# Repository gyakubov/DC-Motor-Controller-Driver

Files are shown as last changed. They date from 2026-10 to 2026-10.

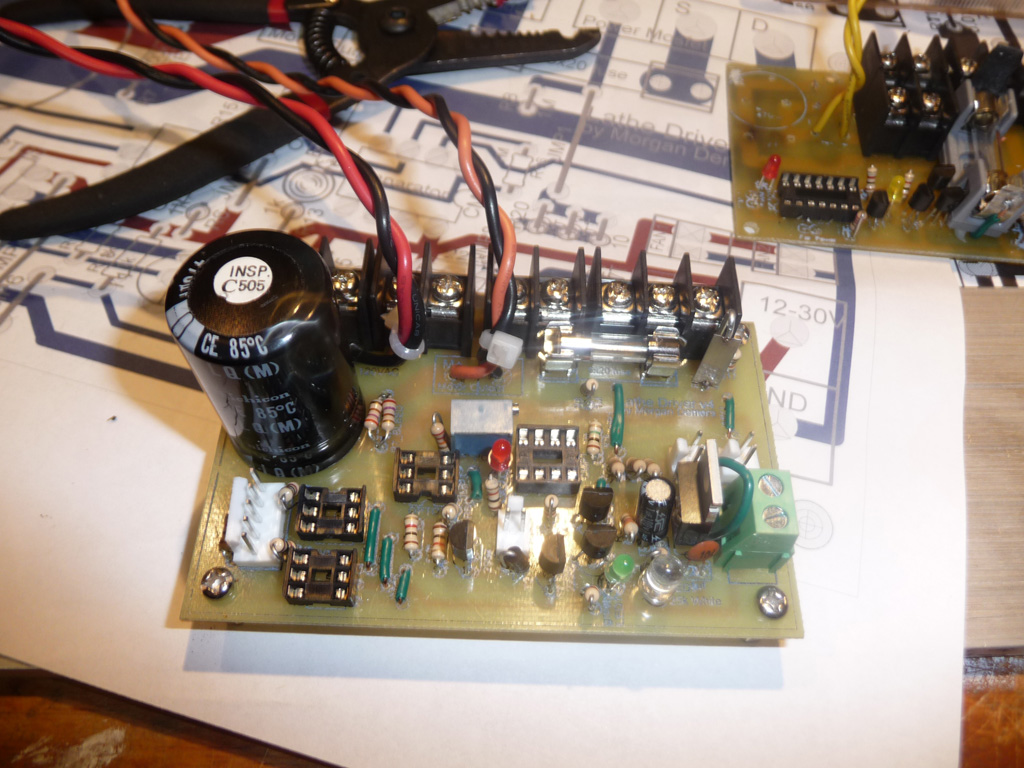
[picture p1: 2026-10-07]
Hardware/Photos/DRIVER_POPULATED.JPG

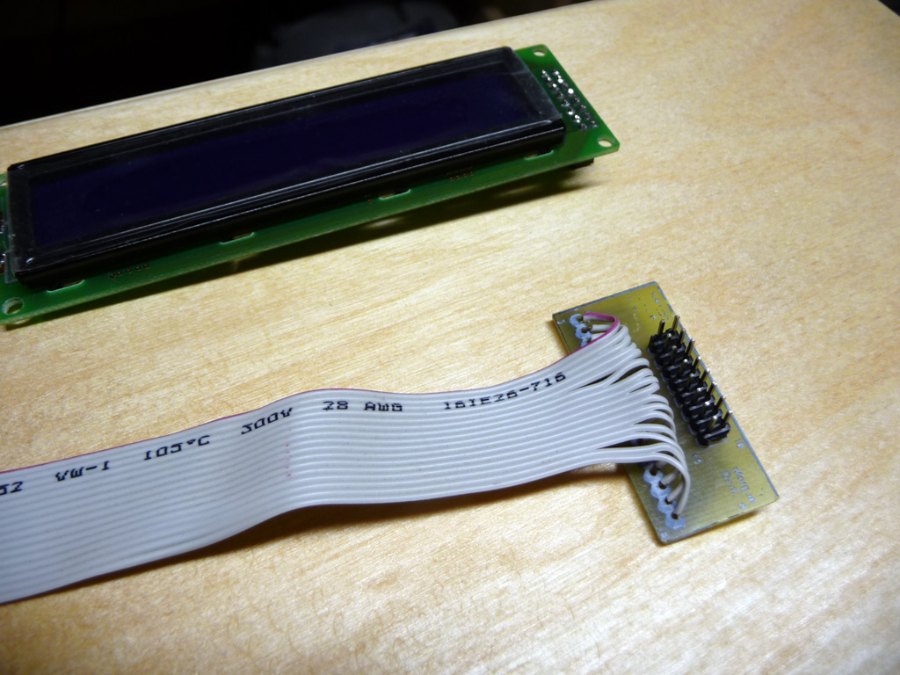
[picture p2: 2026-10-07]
Hardware/Photos/2x8_header_to_1x16_ribbon_and_LCD.jpg

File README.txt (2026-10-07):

DC Motor Controller & Driver README
===================================

This directory has the open source DC Motor Controller & Driver software, board layouts, schematics, and parts list.

For the latest updates by the original author of this project visit:
http://morgandemers.com/?page_id=444

Author: Morgan Demers

+---------+
| LICENSE |
+---------+

This work is licensed under the Creative Commons Attribution-NonCommercial-ShareAlike 3.0 Unported License. To view a copy of this license, visit http://creativecommons.org/licenses/by-nc-sa/3.0/.

+--------------+
| Introduction |
+--------------+

In the winter of 2009 I began working on a Gingery Style metal lathe, as an alternative to buying a chinese made 7x12. It was my desire to attain some casting and machining skills, and in the end to have a lathe with similar capabilities. The original Gingery design calls for cone pulleys and belt changes to get varying speeds with no compensation for load. As I have a background in Computer Engineering, I thought it would be a great opportunity to design a Controller & Driver for a 2hp DC Treadmill Motor for the Lathe. I also wanted a fairly nice & simple digital interface that I could use to control the machine tool. And thus in 2011 I began working on the electronics / software aspect of the project. It is now 2013, my lathe is built, and the Controller, Driver and Software fairly well tested. It has been my end goal to make the project available to anyone who is interested in building a similar Controller for their own machine tool ( this can be used on a lathe, milling machine, drill press, etc... ).

+--------------+
| Dependencies |
+--------------+

Software:

The software was written for the Microchip PIC18LF14K50 Microcontroller, and was developed in the MPLAB v8.76 IDE for the Microchip C18 compiler ( free / lite version ). It may be possible to use MPLAB X, however I have not tested it yet...

I use a PICkit2 to program the Controller. I'd imagine a PICkit3 would work fine as well...

Hardware:

The Board Layouts & Schematics are all done in the free / lite version of Eagle 6.1.0. 

+---------------+
| Prerequisites |
+---------------+

In order to build the Controller / Driver you will need some skills / tools. You should have some experience with etching your own printed circuit boards, soldering on components, etc... I've made a point to not use SMD components to make it a bit easier for those who might have through-hole experience, but not SMD...

To get the software onto the controller you will need a PICkit2 ( or PICkit3 ) programmer. At the very least you will need the PICkit2 programmer software to install the 'hex' file in the Sofware Directory, or you will need the MPLAB IDE with C18 compiler installed to build the project and program the Controller.

To print the board layouts you will need Eagle v6.1.0 ( or newer ).

I've made a point to design the Controller / Driver within the limitations of the free versions of MPLAB IDE, C18 Compiter, Eagle v6.1.0, and thus you should not have to buy any software to get this project to work.

+---------------------+
| Directories & Files |
+---------------------+

LICENSE.txt - contains the license for this piece of software & hardware. Please read, open source though not for commercial use. If making modifications maintain changelog, and please leave the names of prior authors, and url to original source ( http://morgandemers.com/?page_id=444 )

README.txt - this file

Parts_List.xls - Excel Spreadsheet of all the parts required to build the Controller / Driver / Interface

Parts_List.csv - CSV version of Excel Sheet if you don't have Excel

'Software' folder - Contains the PIC18LF14K50 C18 software for the Controller. Load MPLAB v8.76 project file, or you can find pre-compiled HEX file that you could download directly to the Controller board.

'Hardware' folder - Contains all Eagle v6.1.0 Schematics & Board Layouts for this project

'Hardware/Eagle Libraries' folder - Contains any Eagle Library dependencies - only used for QRD1114 part in 'Tachometer' schematic / board.

'Hardware/Photos' folder - Contains some photos of my controller / boards / etc... A bit weak but thought it would be relevant to include some photos.

Hardware/Controller.{sch|brd} - Controller Schematic / Board.

Hardware/Driver.{sch|brd} - Driver Schematic / Board.

Hardware/Tachometer.{sch|brd} - Tachometer Schematic / Board.

Hardware/120VAC.sch - Mains 120VAC connection to Driver Schematic

Hardware/Motor.sch - Connections from Motor to Forward/Reverse Relay to Driver Schematic

Hardware/LCD.sch - Connections from LCD to 2x8_to_1x16 board to 1x16_to_1x16 board to Controller Schematic

Hardware/Interface.sch - Connections from 3 interface buttons and RPM potentiometer to 1x9_to_1x9 board to Controller Schematic

'Encoder Wheels' folder - Contains some sample pdf files of Encoder Wheels that you can print out. I would also recommend you download this encoder wheel software that I currently use to create all my wheels at this point - http://code.google.com/p/wheel-encoder-generator/

+-------------------------+
| Putting It All Together |
+-------------------------+

At some point I may produce a video tutorial of building the controller, driver boards, programming the controller, and hooking everything up to a treadmill motor. That being said, it hasn't been done yet, though you can follow the steps below to get an idea of how to go about building the Controller / Driver.

The Circuit Boards were all made at home using the Toner Transfer Method. I've had fairly good success with Staples Photo Basic Gloss paper and a cheap Laminator that I purchased at Costco. I use Ferric Chloride to etch my boards, and have had no problem doing so. I have recently become aware that the 'Staples Photo Basic Gloss' paper is no longer available, but similar results should be capable when using a Glossy Color Laser paper.

Some suggestions:

i. Heatshrink tubing is a great way to insulate all high voltage wires.
ii. 1/4" Quick Disconnect Connectors work well for 120VAC & Motor Connections ( my treadmill motor came with 1/4" quick disconnects ).

Step 1: LCD
-----------
*refer to LCD.sch, 2x8_to_1x16.{sch|brd}, 1x16_to_1x16.{sch|brd} in Hardware folder for details

a. Start by soldering on the 2-1x8 female headers ( if you purchased the LCD display with the 2x8 solder pads ).

b. Make a 2x8_to_1x16 PCB. You should cut a sufficient length of 16 conductor ribbon cable and solder one end to the 2x8_to_1x16 PCB. The 2x8 male pins will connect directly onto the LCD's female header that you soldered in (a) ( take a look at Hardware/Photos to get an idea of how this looks ).

c. Make a 1x16_to_1x16 PCB. Solder the other end of the ribbon cable to the solder pads on the 1x16_to_1x16 PCB. You will solder on a 1x16 male pin header which will connect to the Controller.

Step 2: Interface
-----------------
*refer to Interface.sch, 1x9_to_1x9.{sch|brd} in Hardware folder for details

a. Make a 1x9_to_1x9 PCB. Make note of the Interface Component positions from the Interface.sch. I'll repeat here for clarity - Pins {1,2} connect to Right Button ( SPST momentary push button - NO ), Pins {3,4} connect to Menu Button ( SPST momentary push button - NO ), Pins {5,6} connect to Left Button ( SPST momentary push button - NO ), Pins {7,8,9} connect to RPM Adjustment Precision Potentiometer ( 5k, Multi-Turn ) - Pin 7 = Ground, Pin 8 = V+, Pin 9 = Variable Pot Voltage.

b. Solder a 1x9 male pin header to the other end of the 1x9_to_1x9 PCB, this will connect to the Controller's 'INTERFACE' header.

Step 3: Controller
------------------
*refer to Controller.{sch|brd} in Hardware folder for details

a. Make the 'Controller' PCB, and solder on the components - Do not insert M1 ( PIC18LF14K50 ) until you do (d) below...

b. Connect the Interface 1x9_to_1x9 PCB to the 'INTERFACE' female header on the Controller.

c. Connect the 1x16_to_1x16 PCB to the 'LCD' female header on the Controller.

d. Connect +5V power to POWER terminal block, hook a multimeter up to VTEST, and adjust P1 until you get 3.4V ( *only if using a PIC18LF... )

e. Turn off +5V power, insert M1 ( PIC18LF14K50 )

f. Connect PICKIT2, Load MPLAB or PICKIT2 Programmer Software. PIC18LF14K50 should be detected.

g. Load the 'DC Motor Controller' software into MPLAB, and Program the PIC18LF14K50

h. Once programmed, disconnect the PICKIT2, LCD should show welcome message ( might have to cycle power first )

i. If 'welcome message' displayed, and now on 'RPM: 0','TRG: ...' menu, test the Interface Buttons, otherwise you will have to debug the Controller Board - possibly bad trace, connection, or misplaced components...

*How to use the interface - Menu Button rotates between sub-menus, and Holding the Menu Buttons and pressing Left or Right will change the main menu. Left and Right buttons alone either increment or decrement menu items, or do other actions as suggested on the LCD ( such as start or stop the motor ).

j. Connect your multimeter to the VTEST ( ground pin ) and the PWM Out pin of the 'DRIVER_OUT' header. On the main menu, set the RPM with the RPM Potentiometer, and then press the 'Left Button' to start the motor. You should see a change in voltage on the multimeter. If you have a Frequency measurement feature, use that to verify the 25khz frequency.

Step 4: Tachometer
------------------
*refer to Tachometer.{sch|brd} in Hardware folder for details

a. Make the 'Tachometer' PCB, and solder on the components. This board is a bit tricky, as it has 2 boards in 1 - you will cut off the smaller board that has the QRD1114, and then solder that board onto the main board such that the QRD1114 is facing outward ( toward the encoder wheel, at least in my setup ).

b. You can cut out a set of 3 conductors from your 16 conductor ribbon cable for the Tachometer cable. Using the 3-pin Molex .100 ( 2.54mm ) KK crimp terminals & housings, create a cable to connect the Tachometer to the Controller via the 'TACH' Male Header.

c. Using a laser printer ( or inkjet, then copied on a laser copier ) print out '16_transistion.pdf' from the 'Encoder Wheels' folder.

d. Connect the Tachometer to the Controller, and then move the encoder wheel printout from (c) in front of the QRD1114 sensor ( needs to be very close to the encoder 1/8" or less ). While transitioning between black & white monitor the LCD to see if the RPM changes at all. You can also go to the second menu ( HOLD Menu and press the Right Button ), then the 3rd sub_menu ( press Menu 3 times ). It should have 'TRG: ..' and 'ENC: ..' displayed. While moving the wheel in front of the sensor you should see the ENC number change ( that is what it is seeing on the encoder in a given sample ).

Step 5: Driver
--------------
*refer to Driver.{sch|brd}, Motor.sch in Hardware folder for details

a. Make the 'Driver' PCB, and solder on the components. Note that AC1, AC2, M+, M- are wire pads, and should have 16 gauge wire soldered in and connected to fully insulated quick disconnect connectors on the other end ( for hooking up to 120VAC & Motor ).

b. You can cut out a set of 5 conductors from your 16 conductor ribbon cable for the Driver cable. Using the 5-pin Molex .100 ( 2.54mm ) KK crimp terminals & housings, create a cable to connect the Driver to the Controller via the 'DRIVER_IN' Male Header.

c. Connect either regulated +12V to POWER_IN ( and short 12VREG ) or connect unregulated +12V-30V to POWER_IN and adjust POT1 until voltage at FAN1 is +12V. You should see the white indicator LED ( LED3 ) turn on with power. When a PWM signal is present from the Controller, you should also see the 'Green' indicator LED ( LED1 ) illuminate ( though brightness will vary depending on the DUTY cycle of the PWM signal ).

d. You can cut out a set of 2 conductors from your 16 conductor ribbon cable for the Relay cable. Using the 2-pin Molex .100 ( 2.54mm ) KK crimp terminals & housings, create a cable to connect the Driver to the Relay ( which is used to reverse the motor ). The 'relay' end of the cable should be soldered to a 1/4" fully insulated female quick disconnects which can be put directly onto the relay drive plug pins. To see how you should connect the Motor to the Relay to the Driver refer to Motor.sch.

e. To set the current at which the 'Current Limit' will trip, hook up your multimeter to pins 3 & 4 of IC1, and adjust 'CSENSE_ADJUST' until voltage matches that of expected voltage across current sensing resistor 'RSENSE'. I use a 0.01ohm current sense resistor, so for a 10A current limit, set 'CSENSE_ADJUST' such that the voltage across pins 3 & 4 of IC1 is 0.1V. If your multimeter is not that sensitive, you can measure the resistance of the 'CSENSE_ADJUST' pot on the same pins. Since you know we are working with a +12V supply, you can use the voltage divider equation ( Vout = Vin*(R2/(R1+R2)) ) to determine the resistance at pins 3 & 4 such that the voltage across it would be 0.1V - for our 10A example, since the pot is a 5k and the upper leg is tied to a 22k resistor, you would do something like 0.1V = 12V*(R2/(22k+5k)) - solving for R2, you get R2 = ~225ohm.

f. To test the reverse relay, connect the relay via the 2 conductor cable made in (d) to the Driver, and on the Interface from the main menu ( when you first start up ) press the 'Menu Button' once. You should see the direction of rotation listed with the option to reverse, press the 'Left Button' to do that. You should hear the relay click, if it does that is ready to go.

Step 6: Testing on Low Voltage Motor
------------------------------------
a. It is best to test the setup out on a low voltage motor ( +12V preferrably ). You will have to bypass the bridge rectifier, and you can easily do this by connecting the lower drive voltage to the output pins of the rectifier with aligator clips, or micro clips. Once done, hookup the smaller motor to the M+, M- board wires. You should fashion a simple motor mount out of wood, and a means of affixing a small encoder wheel to the motor shaft ( I used hot glue - put a glob on the back of the wheel, and then press the motor shaft into the glob before it hardens ). You will have to mount the tachometer in such a way that it is positioned close enough to the wheel for a reading ( you could try and hold it by hand but would be difficult to maintain a consistent distance from the wheel ).

b. If you are not using a 96 transition encoder wheel for this test, you will need to hold down the 'Menu Button' and press the 'Right Button' until you get to the Encoder 'Resolution' menu. You can then use the left and right buttons to change the resolution of the encoder wheel. The setting is for transitions, not just black strips.

c. With the simple motor mount, encoder wheel on motor shaft, and tachometer positioned within 1/8" of the wheel you can proceed to set an RPM, and turn on the motor by pressing the 'Left Button' on the main menu. You should see the motor run and adjust such that RPM: and TRG: are the same. If the motor starts and runs at full speed, adjust the position of the Tachometer as it might be too far away, or too close to get a reading.

d. You can test the 'Reverse' capability by hooking the motor leads up to the 'Reverse Relay' and going to the 'Motor Direction' menu - second sub menu off the main menu. Press the 'Left Button' to switch directions.

Step 7: Testing on High Voltage Treadmill Motor
-----------------------------------------------
a. If everything tested successfully in 'Step 6', you can now test the Controller / Driver with the High Voltage Treadmill Motor. You should enclose the Driver within a grounded case of some sort ( I started off with a gutted ATX power supply ), though I have tested the circuit without it before ( standing some distance away with my hand on a power strip switch ). Caution must be taken as it is extremely dangerous working with a circuit that is connected to 120VAC. The 470uF capacitor will also hold a substantially dangerous charge after the power is removed, and even though there is a 200k bleeder, it takes a few minutes for the capacitor to drain - I have seen quite a few sparks when intentially shorting the terminals of the capacitor with an insulated screw driver, so be careful when you get to this point.

+-----------------------+
| Interface Menu System |
+-----------------------+

You navigate the menu system with Left, Right, and Menu Buttons. To change between 'Menus' you hold the 'Menu' button and press either 'Left' or 'Right' which will rotate forward or backward through the menus. If you go past the last menu, you will end up at the first and visa versa. To change between 'Sub Menus' you simply press the 'Menu' button.

On some menus the Left and Right buttons will increment / decrement a value.

On some menus either the Left or Right buttons will do some action as indicated.

############

Menu 1: Main

  Sub Menu 1 - RPM & RPM Target Display ( Main Menu )

  Sub Menu 2 - Motor Direction - Left Button for Forward or Reverse

  Sub Menu 3 - Indexer

Menu 2: Info

  Sub Menu 1 - Current & Last Sample Errors - ER0 = Current Error, ER1 = Last Error

  Sub Menu 2 - PWM Duty Cycle

  Sub Menu 3 - ( TRG: ) Target Setpoint vs. ( ENC: ) Last Sample

Menu 3: PID Algorithm Constants

  Sub Menu 1 - KP - Proportional Constant Numerator

  Sub Menu 2 - KP - Proportional Constant Denominator

  Sub Menu 3 - KI - Integral Constant Numerator

  Sub Menu 4 - KI - Integral Constant Denominator

  Sub Menu 5 - KD - Derivative Constant Numerator

  Sub Menu 6 - KD - Derivative Constant Denominator

  Sub Menu 7 - FF - Feed Forward Constant Numerator

  Sub Menu 8 - FF - Feed Forward Constant Denominator

Menu 4: Settings

  Sub Menu 1 - Max Duty

  Sub Menu 2 - Max RPM

  Sub Menu 3 - Encoder Resolution

+-----------------------+
| Tuning The Controller |
+-----------------------+

Depending on your particular motor, the PID constants will most likely be slightly different than my own for your own setup. There are quite a few good documents online on how to adjust the constants in order to get a fairly good response.

Setting up Feed Forward:

a. Turn off the PID constants by setting the numerators to 0.

b. Set a desired RPM - 200 or something like that.

c. Go to the Feed Forward Sub Menu, and increase the value until the RPM displayed matches that of your desired RPM target.

d. Increase the RPM via the RPM Adjustment Knob and see if the RPM displayed follows the change made.

* feed forward can be used exclusively for variable speed adjustment if no feedback / load compensation is required. It will help the PID algorithm to not have to work so hard to maintain speed if used in conjunction with KP, KI, KD.

Setting up the PID Constants:

a. Before doing this step you need a way to apply a load to the spindle - possibly by cutting some metal if you are setup for that. I have had ok success holding a blank spindle ( no tools, just the shaft ) with a welder's glove - I don't necessarily recommend this, but it seemed fairly safe when I was initially testing my controller.

b. With the spindle running at some desired RPM ( and hopefully Feed Forward setup to get to that speed without a load on the spindle ), go to the 'KP' sub menu and initially set it to 1/1. The proportional constant of the PID controller will simply apply Error*KP to the PID output ( duty cycle ). So this will give you an instantaneous boost in output from the motor to try and maintain speed.

c. Increase KP's constants until you get to a slight overshoot case where the motor will jump beyond the desired RPM when you load the spindle. Back off KP slightly.

d. Increase KD's constant to eliminate any overshoot and reduce the settling time. Be careful with KD ( mine is typically set to 2/30 or something like this ) as it will add instability to the system if too high. 

e. If you find you have a steady state error ( the system settles at an RPM other than the target ) or you are not getting a fast enough response you should increase KI.

*My current settings for a 2hp treadmill motor with 96 resolution encoder wheel - KP=2/1, KI=3/2, KD=2/30, FF=35/4.

Effects of increasing PID Constants on System:

KP will descrease rise time, increase overshoot, decrease steady state error

KI will decrease rise time, decrease overshoot, increase settling time, eliminate steady state error

KD will decrease overshoot, decrease settling time

+-----------------------+
| Spindle Indexing      |
+-----------------------+

This controller has the capability of indexing a spindle if the Tachometer and Reverse Relay is setup. Having the ability to accurately position a spindle can be of some benefit depending on what you are using the controller for. On a lathe for instance you could use it to cut graduated micrometer dials, or if you had a dremel holder for your toolpost, you could do some really interesting stuff...

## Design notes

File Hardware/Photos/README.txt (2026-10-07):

Sorry for the weak photo folder, it would have been ideal if I had taken more pictures of me making the electronics. I've included a few photos of the Driver, and the completed setup as is currently in my lathe today.

Take note of the INTERFACE PHOTO, basically I'm going directly from the buttons & knob to the 1x9_to_1x9 board via a 9 conductor ribbon cable. The 1x9_to_1x9 board goes from ribbon to male pin header which connects to the female header on the controller. All of the switch debouncing on the momentary push buttons is done on the controller board, so no other components are needed from the buttons / knob to the controller.

Also, from the 2x8_to_1x16 photos you can get an idea of how I setup the connectors for the LCD to Controller. Basically 2x8_to_1x16 board, which has two rows of 1x8 male pin headers, and 16 conductor ribbon cable is soldered directly to the 1x16 pads. The other end of the ribbon cable is soldered to a 1x16_to_1x16 board which has a 1x16 male pin header to connect to the controller.

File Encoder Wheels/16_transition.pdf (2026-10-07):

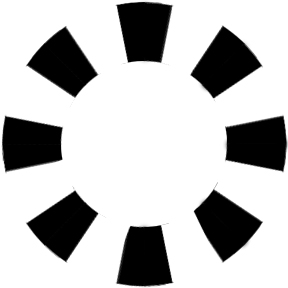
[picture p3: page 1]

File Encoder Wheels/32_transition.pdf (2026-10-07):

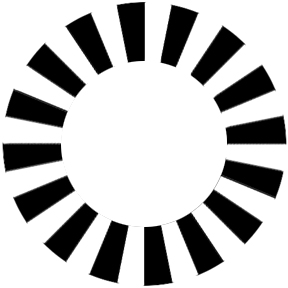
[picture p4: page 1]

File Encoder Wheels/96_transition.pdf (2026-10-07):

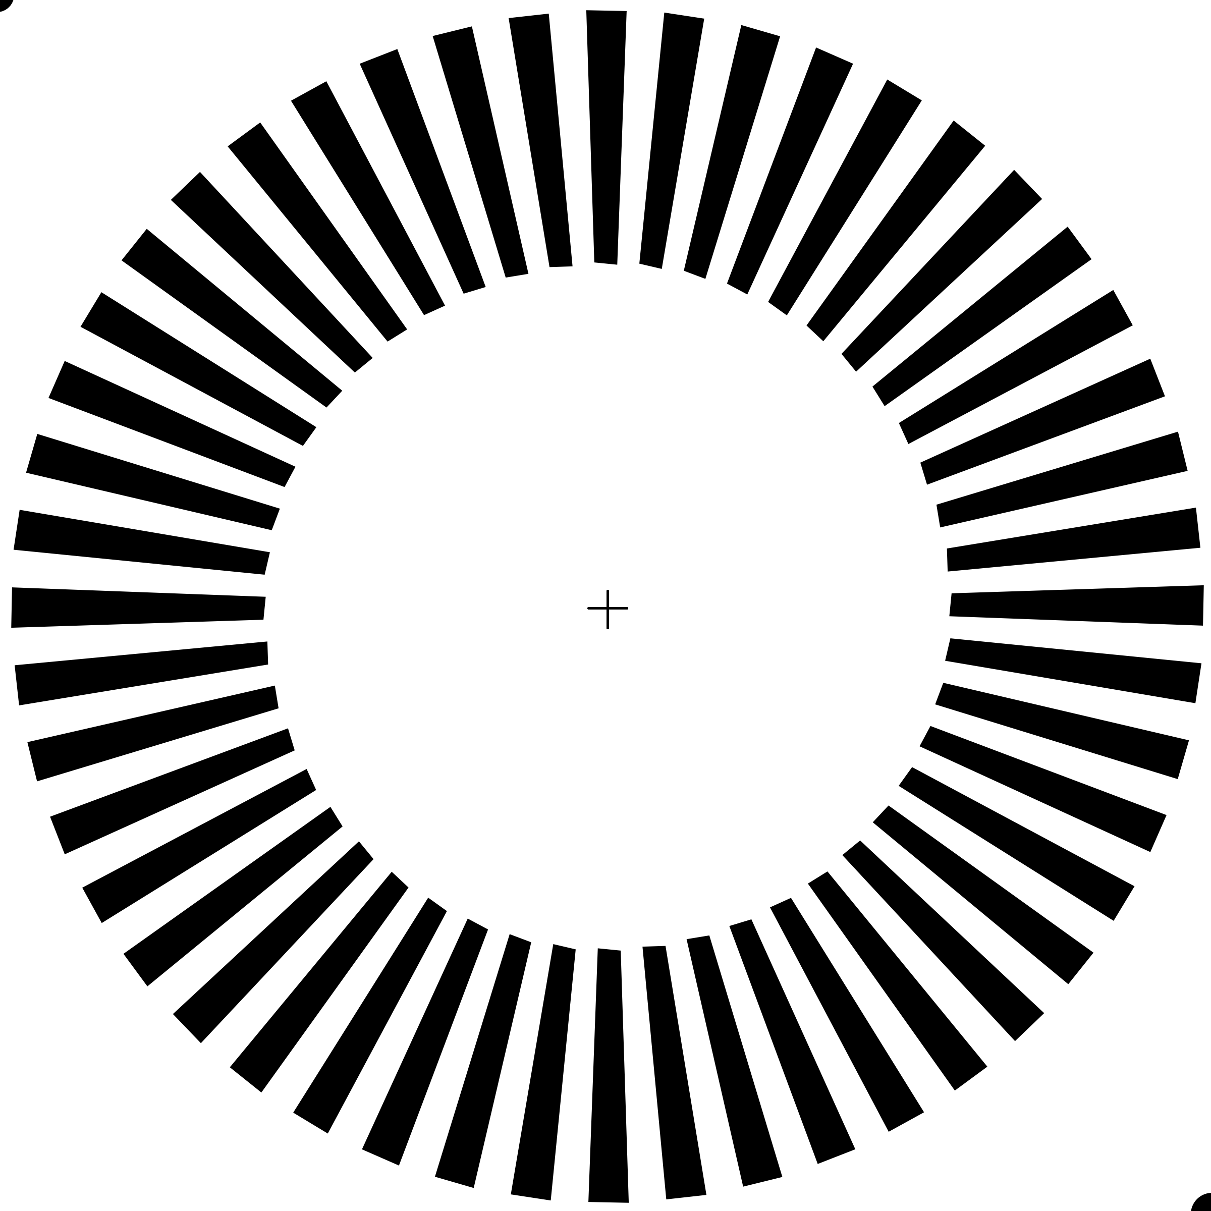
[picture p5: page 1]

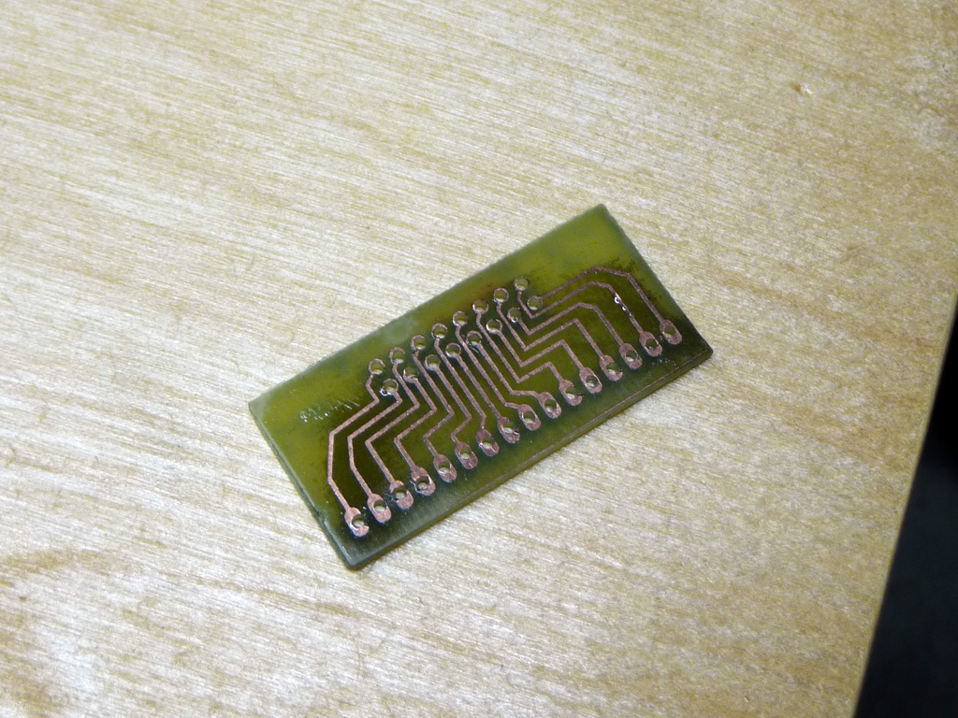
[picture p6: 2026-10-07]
Hardware/Photos/2x8_header_to_1x16_c.JPG

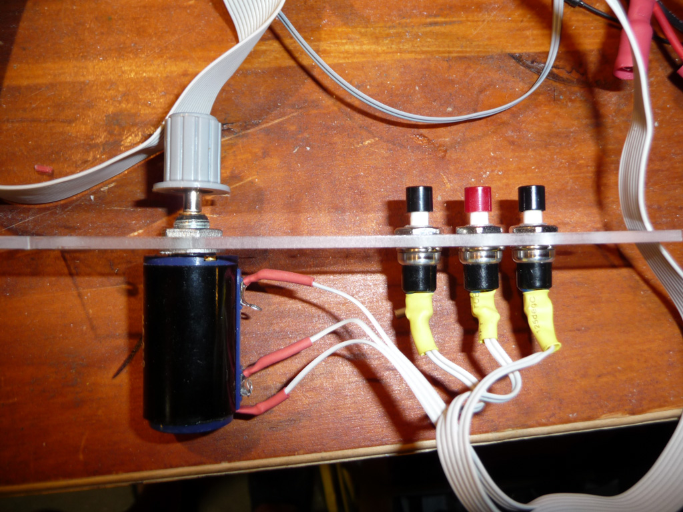
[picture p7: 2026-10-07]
Hardware/Photos/INTERFACE_BUTTONS_KNOB.JPG

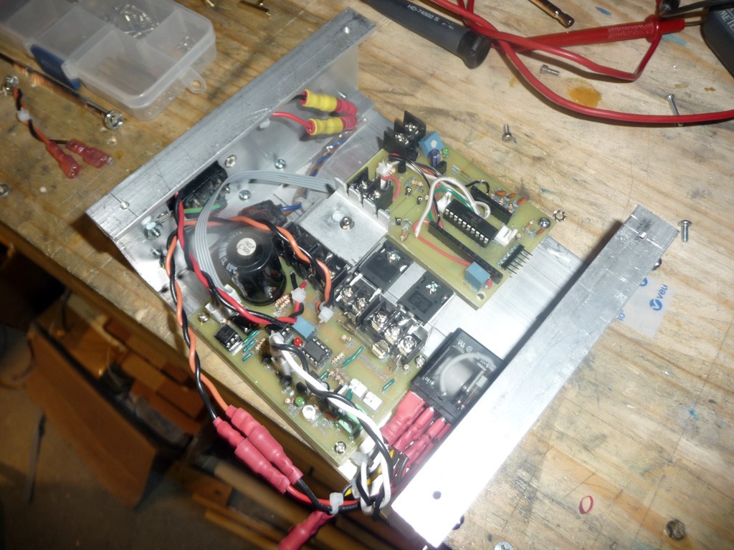
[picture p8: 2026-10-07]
Hardware/Photos/DRIVER_CONTROLLER_IN_BOX.JPG

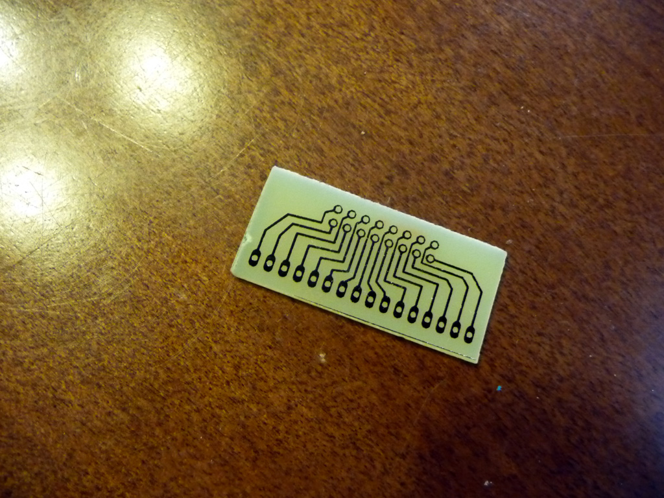
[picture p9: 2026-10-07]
Hardware/Photos/2x8_header_to_1x16_b.JPG

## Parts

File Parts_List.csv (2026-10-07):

Controller Parts ( Controller.sch )
Part Name | Quantity | Schematic Part Name(s) | Part Number | Source | Source Part # |  | Notes
0.1uF Ceramic Disk Capacitors | 5 | C1,C3,C4,C5,C6 | 140-50U5-104M-RC | Mouser | 140-50U5-104M-RC
1uF Electrolytic Capacitor | 1 | C2 | REA010M1HBK-0511P | Mouser | 140-REA010M1HBK-0511P
5 position - Molex KK 2.54mm Lock Header | 1 | DRIVER_OUT | 22-23-2051 | Mouser | 538-22-23-2051
3 position - Molex KK 2.54mm Lock Header | 1 | TACH | 22-23-2031 | Mouser | 538-22-23-2031
2 position - Molex KK 2.54mm Lock Header | 1 | I2C | 22-23-2021 | Mouser | 538-22-23-2021
1x16 Female Header ( 2.54mm ) | 1 | H1 |  | sureelectronics.net | DC-CS11186
1x9 Female Header ( 2.54mm ) | 1 | H2 |  | sureelectronics.net | DC-CS11186
1x2 Female Header ( 2.54mm ) | 1 | VTEST |  | sureelectronics.net | DC-CS11186
1x6 Male 90deg Header ( 2.54mm ) | 1 | PICKIT | 68016-406HLF | Mouser | 649-68016-406HLF
Green LED ( T-1 ) | 1 | LED3 | WP3A8GB | Mouser | 604-WP3A8GD
LM317LZ - 0.1A, 1.2-37V Adjustable Regulator | 1 | LM317LZ | LM317LZ | Mouser | 512-LM317LZ
PIC18LF14K50 | 1 | M1 | PIC18LF14K50-I/P | Mouser | 579-PIC18LF14K50-I/P
500ohm Trim Pot | 1 | P1 | T73YP501KT20 | Mouser | 72-T70YP-500
5kohm Trim Pot | 1 | P2 | T73YP502KT20 | Mouser | 72-T70YP-500 | 5K
2 Pole Terminal Block | 1 | POWER | CS-CO017 | sureelectronics.net | CS-CO017
10kohm Resistor ( 1/4 watt ) | 1 | R2 | MF1/4DCT52R1002F | Mouser | 660-MF1/4DCT52R1002F
1kohm Resistor ( 1/4 watt ) | 3 | R7,R8,R9 | MF1/4DCT52R1001F | Mouser | 660-MF1/4DCT52R1001F
470ohm Resistor ( 1/4 watt ) | 1 | R3 | MF1/4DCT52R4700F | Mouser | 660-MF1/4DCT52R4700F
150ohm Resistor ( 1/4 watt ) | 1 | R4 | MF1/4DCT52R1500F2 | Mouser | 660-MF1/4DCT52R1500F2
20pin IC Socket | 1 | M1 | DILB20P-223TLF | Mouser | 649-DILB20P-223TLF
24x2 LCD Character Display | 1 |  | NHD-0224AZ-FSW-GBW | Mouser | 763-0224AZ-FSW-GBW
Programmer Parts
Part Name | Quantity | Schematic Part Name(s) | Part Number | Source | Source Part # |  | Notes
PICKIT2 | 1 |  | PG164120 | Microchipdirect.com | PG164120
Driver Parts ( Driver.sch )
Part Name | Quantity | Schematic Part Name(s) | Part Number | Source | Source Part # |  | Notes
LM317TG - 1.5A, 1.2-37V Adjustable Regulator | 1 | 317T | LM317TG | Mouser | 863-LM317TG
Bridge Rectifier 8A 600V | 1 | BR1 | GBU8J | Mouser | 512-GBU8J |  | Replaces TS20P03G (20A/200V). GBU8J is only rated 8A continuous vs the 15A F1 fuse rating - verify actual motor current stays well under this before relying on it.
0.1uF Ceramic Disk Capacitors | 1 | C1 | 140-50U5-104M-RC | Mouser | 140-50U5-104M-RC
1uF Electrolytic Capacitor | 1 | C2 | REA010M1HBK-0511P | Mouser | 140-REA010M1HBK-0511P
470uF 200V Electrolytic Capacitor | 1 | C4 | SLP471M200C3P3 | Mouser | 598-SLP471M200C3P3
5 position - Molex KK 2.54mm Lock Header | 1 | CONTROLLER_IN | 22-23-2051 | Mouser | 538-22-23-2051
2 position - Molex KK 2.54mm Lock Header | 3 | FAN1,FAN2,REV | 22-23-2021 | Mouser | 538-22-23-2021
5kohm Trim Pot | 2 | CSENSE_ADJUST, POT1 | T73YP502KT20 | Mouser | 72-T70YP-500 | 5K
Motor Flyback Diode - Ultrafast 1200V | 1 | MOTOR_FLYBACK | STTH6012W | Mouser | 511-STTH6012W
Relay Flyback Diode | 1 | D1 | 1N4148TA | Mouser | 512-1N4148TA
Fuse Holder Clips ( 5mm ) | 2 | F1 | 01000020Z | Mouser | 576-01000020Z
Fuse 5x20 250V 12.5A | 1 | F1 | 1.1015 | Mouser | 693-0001.1015
LM393AN Comparator | 1 | IC1 | LM393AN | Mouser | 512-LM393AN
Green LED ( T-1 ) | 1 | LED1 | WP3A8GB | Mouser | 604-WP3A8GD
Red LED ( T-1 ) | 1 | LED2 | WP710A10ID | Mouser | 604-WP710A10ID
25k White LED ( 5mm ) | 1 | LED3 | C503B-WAN-CBADA152 | Mouser | 941-C503BWANCBADA152
Logic Output Optocouplers | 3 | OK1,OK2,OK3 | H11L2 | Mouser | 638-H11L2
2 Pole Terminal Block | 1 | POWER_IN | CS-CO017 | sureelectronics.net | CS-CO017
Power Mosfet - 250V, 57A 33mOhm, 99nC | 1 | Q1 | IRFP4332PBF | Mouser | 638-IRFP4332PBF
Heatsinks | 3 |  |  |  |  |  | My aluminum case provides the heatsink for Q1 ( drive mosfet ) and MOTOR_FLYBACK. If you do not have a case that can act as a big heatsink, these two components will need a fairly decent sized heatsink(s). I also have a smaller heatsink on BR1 ( the bridge rectifier )
1kohm Resistor ( 1/4 watt ) | 8 | R1,R6,R9,R10,R12,R13,R17,R19 | MF1/4DCT52R1001F | Mouser | 660-MF1/4DCT52R1001F
1Mohm Resistor ( 1/4 watt ) | 2 | R8,R16 | MF1/4DCT52R1004F | Mouser | 660-MF1/4DCT52R1004F
150ohm Resistor ( 1/4 watt ) | 1 | R4 | MF1/4DCT52R1500F2 | Mouser | 660-MF1/4DCT52R1500F2
200kohm Resistor ( 1/4 watt ) | 1 | R7_BLEED | MF1/4DCT52R2003F | Mouser | 660-MF1/4DCT52R2003F
22kohm Resistor ( 1/4 watt ) | 1 | R15 | MF1/4DC2202F | Mouser | 660-MF1/4DC2202F
10ohm Resistor ( 1/4 watt ) | 3 | R20,R21,R22 | MF1/4DC10R0F | Mouser | 660-MF1/4DC10R0F
0.01ohm, 3 watt Current Sense Resistor | 1 | RSENSE | 630HR010E | Mouser | 588-630HR010E
PN2907 BJT PNP Transistor | 1 | T1 | PN2907ATF | Mouser | 512-PN2907ATF |  | T2/T3/T4 removed - replaced by IC2 (MIC4422) gate driver. T1 remains - it drives the REV MOSFET via OK2, unrelated to the motor gate drive.
MIC4422 9A Low-Side MOSFET Driver (PDIP-8) | 1 | IC2 | MIC4422YN | Mouser | 998-MIC4422YN |  | Replaces discrete T2/T3/T4/R5/R18 push-pull driver. PLACEHOLDER WIRED in Driver1: IC2 is currently an LM393 DIP-8 symbol (no exact MIC4422 part in library) standing in for the real part - swap the symbol/footprint for a real MIC4422YN before fabrication. Wired as: +IN1->PWM net, -IN1->GND (reference), OUT1->old gate-drive node (feeds DRV_0/Q1 gate network and LED1), VCC->+12V, GND->GND. Add a 0.1-1uF ceramic decoupling cap from VCC to GND next to the IC.
8pin IC Socket | 1 | IC1 | DILB8P-223TLF | Mouser | 649-DILB8P223TLF
6pin IC Socket | 3 | OK1,OK2,OK3 | ICS-306-T | Mouser | 737-ICS-306-T
Motor Hookup & Reverse Parts ( Motor.sch )
Part Name | Quantity | Schematic Part Name(s) | Part Number | Source | Source Part # |  | Notes
12VDC, 10A DPDT Plug-In Relay | 1 |  | 275-218 | Radioshack | 275-218 |  | Could use other relay, even with solder leads - the plug in relays work well with connectors terminated by female 1/4" fully insulated quick disconnects
1/4" Fully Insulated Quick Disconnects | 2 |  | 64-3133, 64-3131 | Radioshack | 64-3133, 64-3131 |  | Two part numbers, one for blue and one for red, comes in packs of 10 - use for both Motor & 120VAC lines
16 gauge stranded hookup wire |  |  |  | Radioshack
120VAC Line In Parts ( 120VAC.sch )
Part Name | Quantity | Schematic Part Name(s) | Part Number | Source | Source Part # |  | Notes
16 gauge stranded hookup wire | 1 |  |  | Radioshack
1/4" Fully Insulated Quick Disconnects | 2 |  | 64-3133, 64-3131 | Radioshack | 64-3133, 64-3131 |  | Two part numbers, one for blue and one for red, comes in packs of 10 - use for both Motor & 120VAC lines
Inline Fuse Holder ( 20A ) - 1-1/4x1/4 | 1 |  | 270-1217 | Radioshack | 270-1217
15A Fuse - 1-1/4x1/4 | 1 |  | BK/AGC-15-R | Mouser | 504-BK/AGC-15-R
Tachometer Parts ( Tachometer.sch )
Part Name | Quantity | Schematic Part Name(s) | Part Number | Source | Source Part # |  | Notes
0.1uF Ceramic Disk Capacitors | 1 | C1 | 140-50U5-104M-RC | Mouser | 140-50U5-104M-RC
1N914 Diode ( 4ns ) | 3 | D1,D2,D3 | 1N914 | Mouser | 512-1N914
3 position - Molex KK 2.54mm Lock Header | 1 | X1 | 22-23-2031 | Mouser | 538-22-23-2031
1kohm Resistor ( 1/4 watt ) | 1 | R3 | MF1/4DCT52R1001F | Mouser | 660-MF1/4DCT52R1001F
10kohm Resistor ( 1/4 watt ) | 1 | R2 | MF1/4DCT52R1002F | Mouser | 660-MF1/4DCT52R1002F
680ohm Resistor ( 1/4 watt ) | 1 | R1 | MF1/4DCT52R6800F | Mouser | 660-MF1/4DCT52R6800F
PN2222 BJT NPN Transistor | 1 | T1 | PN2222ATFR | Mouser | 512-PN2222ATFR
1x3 Male 90deg Header ( 2.54mm ) | 1 | JP1 | 69191-403HLF | Mouser | 649-69191-403HLF
QRD1114 - Reflective IR Sensor | 1 | S1 | QRD1114 | Mouser | 512-QRD1114
Connector Parts
Part Name | Quantity | Schematic Part Name(s) | Part Number | Source | Source Part # |  | Notes
Molex KK 2.54mm Crimp Terminals | 16 |  | 08-50-0114 | Mouser | 538-08-50-0114
3 position - Molex KK 2.54mm Crimp Housing | 2 |  | 22-01-2037 | Mouser | 538-22-01-2037
5 position - Molex KK 2.54mm Crimp Housing | 2 |  | 22-01-2057 | Mouser | 538-22-01-2057
16 Conductor Ribbon Cable | 2 |  | 3302/16-CUT-LENGTH | Mouser | 517-3302/16
LCD Connector Parts ( LCD.sch )
Part Name | Quantity | Schematic Part Name(s) | Part Number | Source | Source Part # |  | Notes
1x8 Female Header ( 2.54mm ) | 2 |  |  | sureelectronics.net | DC-CS11186 |  | LCD has 2x8 connector pads, use 2 - 1x8 headers
LCD to Ribbon Parts ( LCD.sch )
Part Name | Quantity | Schematic Part Name(s) | Part Number | Source | Source Part # |  | Notes
1x8 Male Header ( 2.54mm ) | 2 | H1 | DC-CS11185 | sureelectronics.net | DC-CS11185
LCD Ribbon to Controller Parts ( LCD.sch )
Part Name | Quantity | Schematic Part Name(s) | Part Number | Source | Source Part # |  | Notes
1x16 Male Header ( 2.54mm ) | 1 | H2 | DC-CS11185 | sureelectronics.net | DC-CS11185
Interface Parts ( Interface.sch )
Part Name | Quantity | Schematic Part Name(s) | Part Number | Source | Source Part # |  | Notes
5k - 10 turn precision potentiometer ( RPM ) | 1 |  | 3590S-2-103L | Mouser | 652-3590S-2-103L
Knob for RPM potentiometer | 1 |  | 1100 | Mouser | 5164-1100
Red Push Button Switch ( panel mount ) | 1 |  | 103-1012-EVX | Mouser | 103-1012-EVX
Black Push Button Switch ( panel mount ) | 2 |  | 103-1013-EVX | Mouser | 103-1013-EVX
Interface to Controller Parts ( Interface.sch )
Part Name | Quantity | Schematic Part Name(s) | Part Number | Source | Source Part # |  | Notes
1x9 Male Header ( 2.54mm ) | 1 | H2 | DC-CS11185 | sureelectronics.net | DC-CS11185
PCB Making Parts
Part Name | Quantity | Schematic Part Name(s) | Part Number | Source | Source Part # |  | Notes
12x12 Copper Clad Board ( singled sided ) | 1 |  |  | Amazon - Parts Express | ASIN:B000P7ALZC |  | http://www.amazon.com/gp/product/B000P7ALZC/ref=oh_details_o00_s00_i00
Ferric Chloride Etching Chemical | 1 |  | 276-1535 | Radioshack | 276-1535 |  | http://www.radioshack.com/product/index.jsp?productId=2102868#tabsetBasic
Laser Printer | 1
Glossy Color Laser Paper | 1 |  | 863054 | Staples.com | 863054
Laminator or Iron | 1
Drill Press | 1
Tungsten Carbide Micro Drills | 1

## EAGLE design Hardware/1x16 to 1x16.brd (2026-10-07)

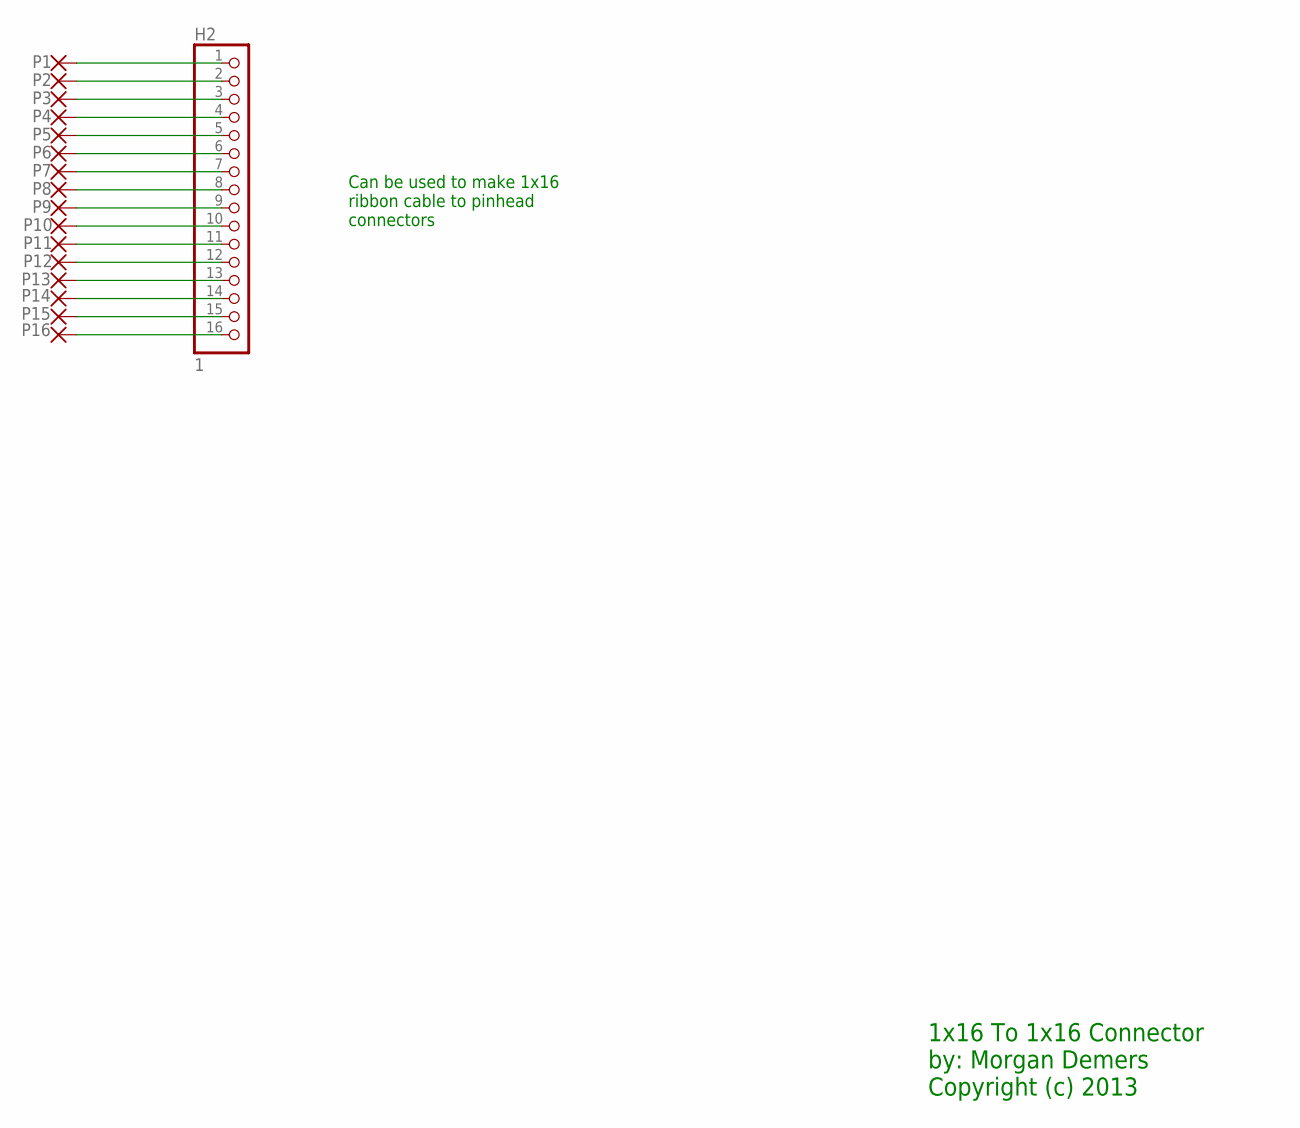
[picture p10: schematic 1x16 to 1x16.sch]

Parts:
H2: 1; 1X16
P1, P2, P3, P4, P5, P6, P7, P8, P9, P10, P11, P12, P13, P14, P15, P16: 1,6/0,9

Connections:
S$1: H2.1, P1.1
S$2: H2.2, P2.1
S$3: H2.3, P3.1
S$4: H2.4, P4.1
S$5: H2.5, P5.1
S$6: H2.6, P6.1
S$7: H2.7, P7.1
S$8: H2.8, P8.1
S$9: H2.9, P9.1
S$10: H2.10, P10.1
S$11: H2.11, P11.1
S$12: H2.12, P12.1
S$13: H2.13, P13.1
S$14: H2.14, P14.1
S$15: H2.15, P15.1
S$16: H2.16, P16.1

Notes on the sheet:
1x16 To 1x16 Connector by: Morgan Demers Copyright (c) 2013
Can be used to make 1x16 ribbon cable to pinhead connectors

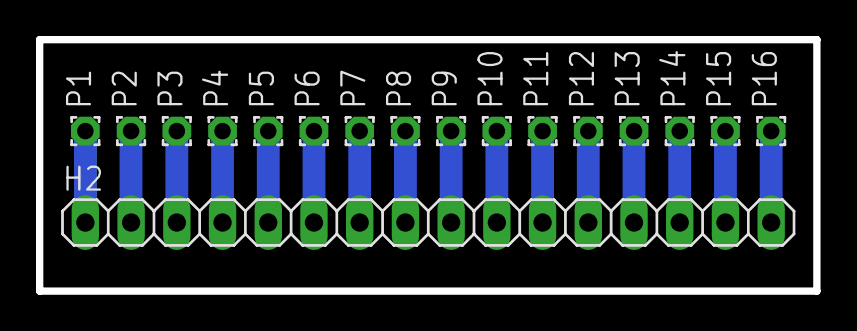
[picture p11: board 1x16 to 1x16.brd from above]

Board: 2 copper layers, 43.2 x 14.0 mm, 17 parts (0 on the bottom side), 16 nets.

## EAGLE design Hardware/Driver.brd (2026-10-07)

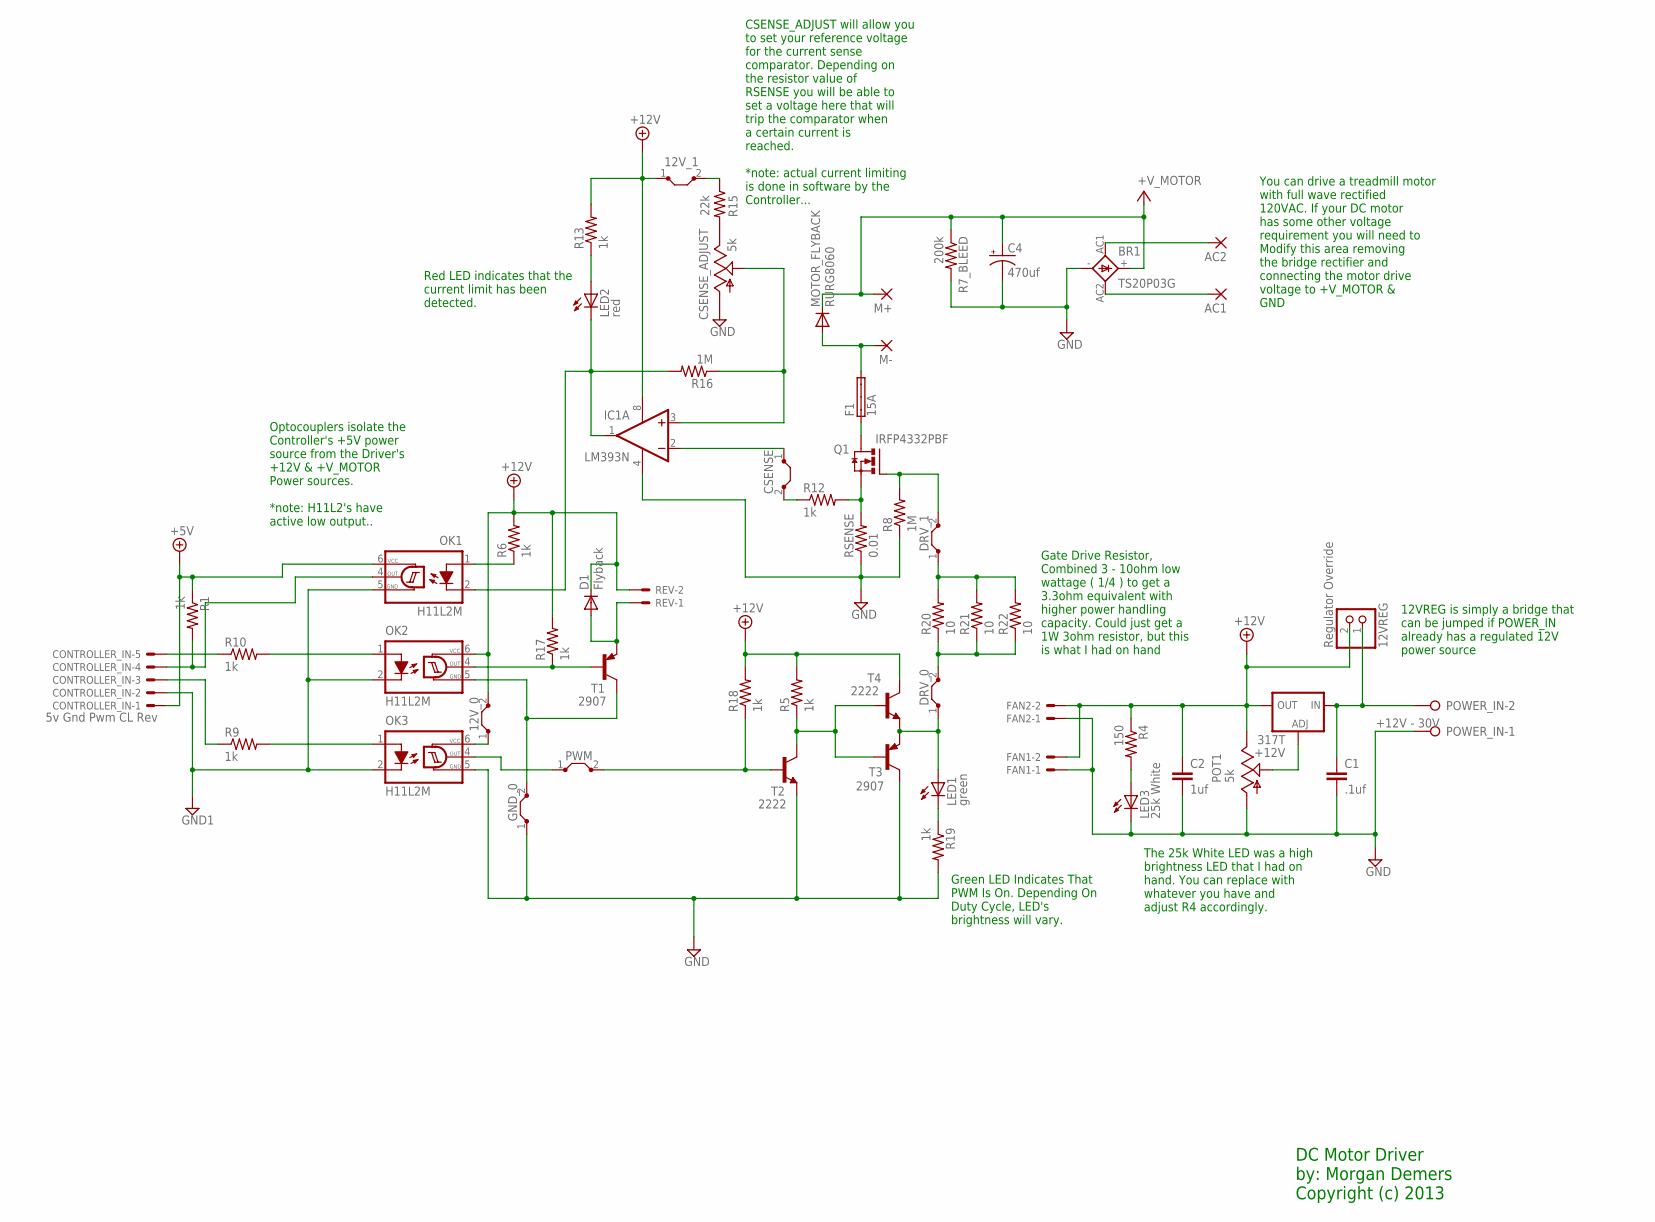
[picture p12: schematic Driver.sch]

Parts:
12VREG: Regulator Override; 1X02
12V_0: J10MM; 10
12V_1: J5MM; 05
317T: +12V; 317TS
AC1, AC2: WIREPAD4,16O1,6; 4,16O1,6
BR1: TS20P03G; FB32
C1: .1uf; C2.5-3
C2: 1uf; C2.5-3
C4: 470uf; EB22,5D
CONTROLLER_IN: 5v Gnd Pwm CL Rev; 22-23-2051
CSENSE: J7MM; 07
CSENSE_ADJUST: 5k; B25P
D1: Flyback; D-2.5
DRV_0: J5MM; 05
DRV_1: J12MM; 12
F1: 15A; SHK20L
FAN1, FAN2: 22-23-2021
GND_0: J7MM; 07
IC1: LM393N; DIL08
LED1: green; LED3MM
LED2: red; LED3MM
LED3: 25k White; LED3MM
M+: WIREPAD4,16O1,6; 4,16O1,6
M-: WIREPAD4,16O1,6; 4,16O1,6
MOTOR_FLYBACK: RURG8060; TO220ACS
OK1, OK2, OK3: H11L2M; DIL06
POT1: 5k; B25P
POWER_IN: +12V - 30V; W237-132
PWM: J5MM; 05
Q1: IRFP4332PBF; TO247BV
R1, R18: 1k; 0204/7
R4: 150; 0204V
R5, R6, R9, R10, R12, R13, R19: 1k; 0204V
R7_BLEED: 200k; 0207/10
R8: 1M; 0204V
R15: 22k; 0204V
R16: 1M; 0204/5
R17: 1k; 0204/5
R20, R21, R22: 10; 0204V
REV: 22-23-2021
RSENSE: 0.01; 0204V
T1, T3: 2907; TO92-CBE
T2, T4: 2222; TO92-EBC

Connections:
+5V: CONTROLLER_IN.1, OK1.6 (VCC), R1.1
+12V: 12VREG.2, 12V_0.2, 12V_1.1, 317T.2 (OUT), C2.1, D1.C, FAN1.2, FAN2.2, IC1.8 (V+), OK2.6 (VCC), POT1.E, R4.1, R5.2, R6.2, R13.2, R17.2, R18.2, REV.2, T4.C
GND: BR1.-, C1.2, C2.2, C4.-, CSENSE_ADJUST.A, FAN1.1, FAN2.1, GND_0.1, IC1.4 (V-), LED3.K (C), OK3.5 (GND), POT1.A, POWER_IN.1, R7_BLEED.2, R8.1, R19.2, RSENSE.1, T2.E, T3.C
GND1: CONTROLLER_IN.2, OK1.5 (GND), OK2.2 (C), OK3.2 (C)
unnamed: OK2.1 (A), R10.2
unnamed: OK3.4 (OUT), PWM.1
unnamed: CSENSE.1, IC1.2 (-IN)
S$1: CONTROLLER_IN.3, R9.1
S$2: PWM.2, R18.1, T2.B
S$4: Q1.S, R12.2, RSENSE.2
S$6: 317T.1 (ADJ), POT1.S
S$7: CONTROLLER_IN.5, R10.1
S$8: CONTROLLER_IN.4, OK1.4 (OUT), R1.2
S$9: R5.1, T2.C, T3.B, T4.B
S$10: 12V_1.2, R15.1
S$11: LED3.A, R4.2
S$12: IC1.1 (OUT), LED2.K (C), OK1.2 (C), R16.2
S$13: DRV_0.2, R20.1, R21.1, R22.1
S$14: OK2.4 (OUT), R17.1, T1.B
S$16: DRV_1.2, Q1.G, R8.2
S$20: F1.1A, Q1.D
S$21: AC1.1, BR1.AC2
S$22: OK1.1 (A), R6.1
S$23: AC2.1, BR1.AC1
S$25: F1.2A, M-.1, MOTOR_FLYBACK.A
S$26: 12V_0.1, OK3.6 (VCC)
S$27: CSENSE_ADJUST.E, R15.2
S$32: OK3.1 (A), R9.2
S$34: CSENSE.2, R12.1
S$45: CSENSE_ADJUST.S, IC1.3 (+IN), R16.1
S$50: LED1.K (C), R19.1
S$51: LED2.A, R13.1
S$52: DRV_1.1, R20.2, R21.2, R22.2
S$54: 12VREG.1, 317T.3 (IN), C1.1, POWER_IN.2
S$129: DRV_0.1, LED1.A, T3.E, T4.E
S$171: D1.A, REV.1, T1.E
S$448: GND_0.2, OK2.5 (GND), T1.C
V+: BR1.+, C4.+, M+.1, MOTOR_FLYBACK.C, R7_BLEED.1

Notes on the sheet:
Gate Drive Resistor, Combined 3 - 10ohm low wattage ( 1/4 ) to get a 3.3ohm equivalent with higher power handling capacity. Could just get a 1W 3ohm resistor, but this is what I had on hand
Green LED Indicates That PWM Is On. Depending On Duty Cycle, LED's brightness will vary.
12VREG is simply a bridge that can be jumped if POWER_IN already has a regulated 12V power source
Red LED indicates that the current limit has been detected.
You can drive a treadmill motor with full wave rectified 120VAC. If your DC motor has some other voltage requirement you will need to Modify this area removing the bridge rectifier and connecting the motor drive voltage to +V_MOTOR & GND
CSENSE_ADJUST will allow you to set your reference voltage for the current sense comparator. Depending on the resistor value of RSENSE you will be able to set a voltage here that will trip the comparator when a certain current is reached. *note: actual current limiting is done in software by the Co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
Optocouplers isolate the Controller's +5V power source from the Driver's +12V & +V_MOTOR Power sources. *note: H11L2's have active low output..
The 25k White LED was a high brightness LED that I had on hand. You can replace with whatever you have and adjust R4 accordingly.
DC Motor Driver by: Morgan Demers Copyright (c) 2013

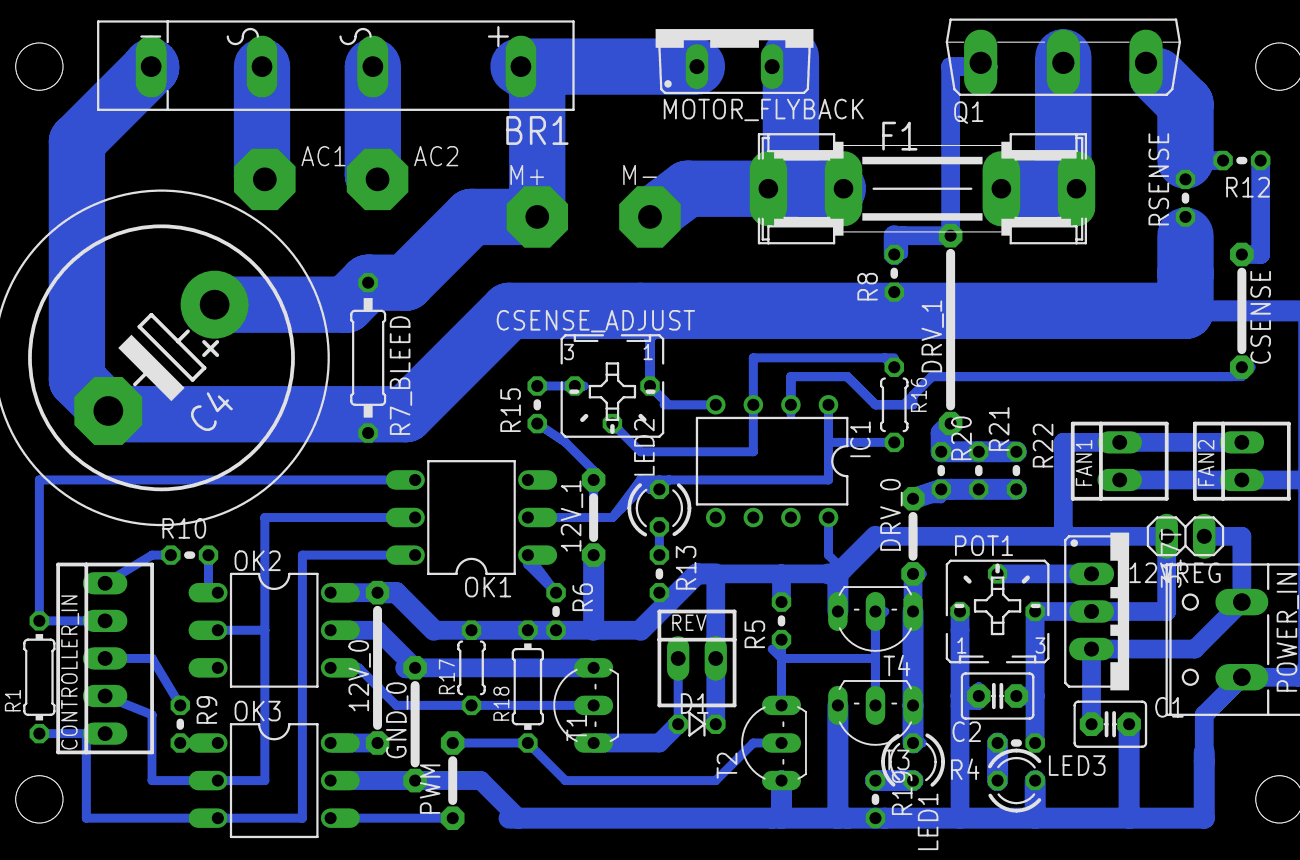
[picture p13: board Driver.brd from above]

Board: 2 copper layers, 58 parts (0 on the bottom side), 38 nets.

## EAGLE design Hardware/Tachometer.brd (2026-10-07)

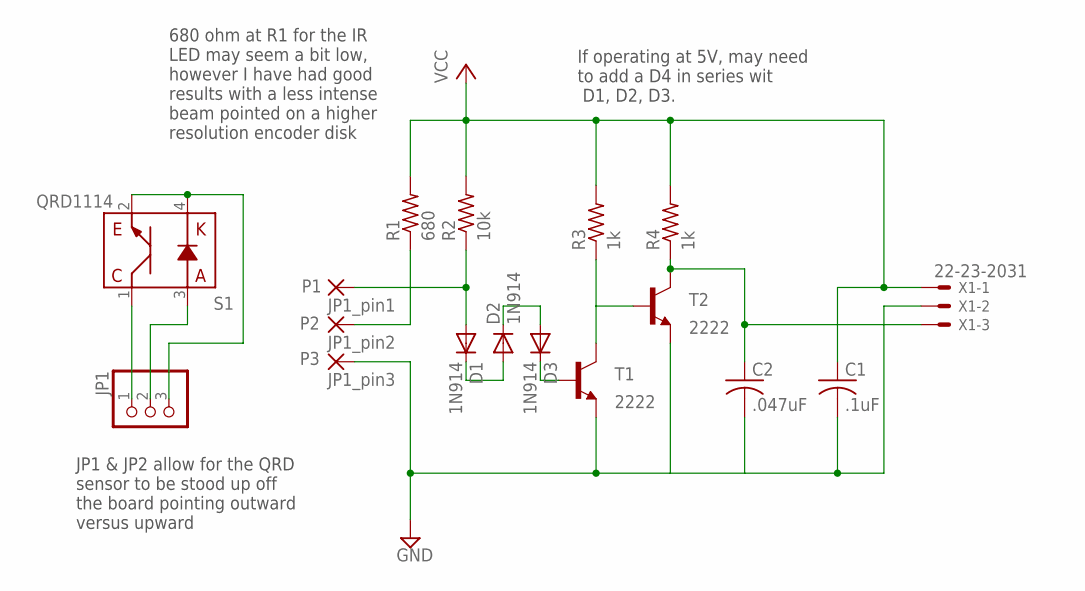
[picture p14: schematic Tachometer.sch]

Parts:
C1: .1uF; C025-024X044
C2: .047uF; C025-024X044
D1, D2, D3: 1N914; D-2.5
JP1: 1X03/90
P1: JP1_pin1; 1,6/0,9
P2: JP1_pin2; 1,6/0,9
P3: JP1_pin3; 1,6/0,9
R1: 680; 0204/5
R2: 10k; 0204/5
R3, R4: 1k; 0204/5
S1: QRD1114
T1, T2: 2222; TO92-EBC
X1: 22-23-2031

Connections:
GND: C1.2, C2.2, P3.1, T1.E, T2.E, X1.2
unnamed: D1.A, P1.1, R2.1
unnamed: R3.1, T1.C, T2.B
unnamed: JP1.3, S1.2 (C), S1.4 (K)
unnamed: JP1.2, S1.3 (A)
unnamed: JP1.1, S1.1 (E)
unnamed: P2.1, R1.1
unnamed: D1.C, D2.A
unnamed: D2.C, D3.A
unnamed: D3.C, T1.B
unnamed: C2.1, R4.1, T2.C, X1.3
VCC: C1.1, R1.2, R2.2, R3.2, R4.2, X1.1

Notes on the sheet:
JP1 & JP2 allow for the QRD sensor to be stood up off the board pointing outward versus upward
680 ohm at R1 for the IR LED may seem a bit low, however I have had good results with a less intense beam pointed on a higher resolution encoder disk
If operating at 5V, may need to add a D4 in series wit D1, D2, D3.

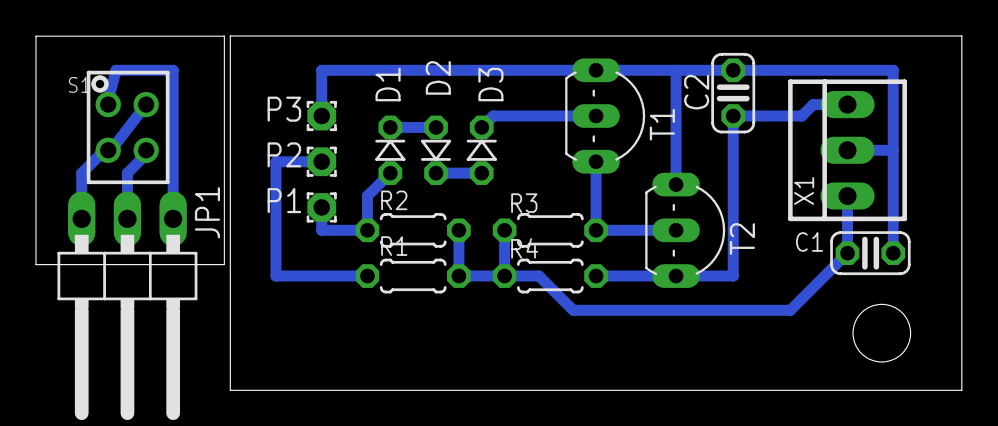
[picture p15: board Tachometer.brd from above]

Board: 2 copper layers, 51.4 x 19.7 mm, 17 parts (0 on the bottom side), 12 nets.

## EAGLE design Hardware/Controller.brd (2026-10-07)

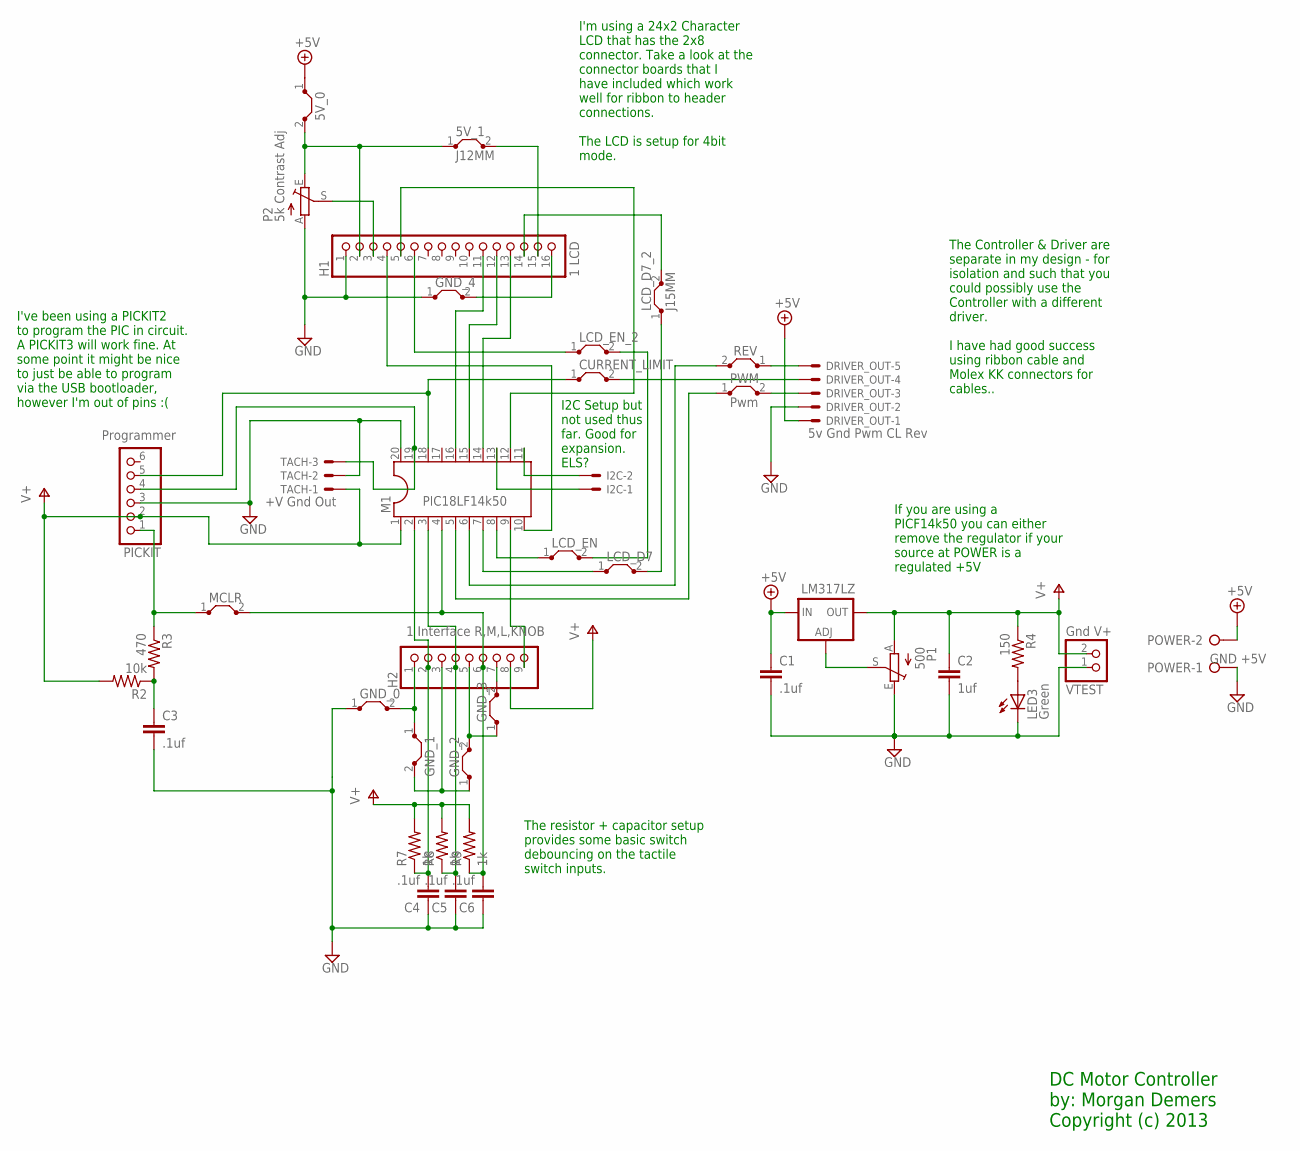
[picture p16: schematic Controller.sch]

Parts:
5V_0: J5MM; 05
5V_1: J12MM; 12
C1, C3: .1uf; C2.5-3
C2: 1uf; C2.5-3
C4, C5, C6: .1uf; C5B2.5
CURRENT_LIMIT: J30MM; 30
DRIVER_OUT: 5v Gnd Pwm CL Rev; 22-23-2051
GND_0, GND_4: J10MM; 10
GND_1, GND_2, GND_3: J5MM; 05
H1: 1 LCD; 1X16
H2: 1 Interface R,M,L,KNOB; 1X09
I2C: 22-23-2021
LCD_D7: J7MM; 07
LCD_D7_2: J15MM; 15
LCD_EN: J7MM; 07
LCD_EN_2: J7MM; 07
LED3: Green; LSU260
LM317LZ: 317L
M1: PIC18LF14k50; DIL20
MCLR: J15MM; 15
P1: 500; B25P
P2: 5k Contrast Adj; B25P
PICKIT: Programmer; 1X06/90
POWER: GND +5V; W237-132
PWM: Pwm; 07
R2: 10k; 0204V
R3: 470; 0204V
R4: 150; 0204V
R7, R8, R9: 1k; 0204V
REV: J10MM; 10
TACH: +V Gnd Out; 22-23-2031
VTEST: Gnd V+; 1X02

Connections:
+5V: 5V_0.1, C1.1, DRIVER_OUT.1, LM317LZ.3 (IN), POWER.2
+5V_J0: 5V_0.2, 5V_1.1, H1.2, P2.E
GND: C1.2, C2.2, C3.2, C4.1, C5.1, C6.1, DRIVER_OUT.2, GND_0.1, GND_4.1, H1.1, LED3.K (C), M1.20, P1.E, P2.A, PICKIT.3, POWER.1, TACH.2, VTEST.1
GND_J0: GND_0.2, GND_1.1, H2.1
GND_J1: GND_1.2, GND_2.1, H2.3
GND_J3: GND_2.2, GND_3.1, H2.5
GND_J4: GND_3.2, H2.7
LMADJ: LM317LZ.1 (ADJ), P1.S
unnamed: 5V_1.2, H1.15
unnamed: LED3.A, R4.2
unnamed: GND_4.2, H1.16
S$2: MCLR.1, PICKIT.1, R3.1
S$3: I2C.2, M1.11
S$4: H2.9, M1.9
S$5: H1.3, P2.S
S$6: H1.14, LCD_D7_2.2
S$7: H1.6, LCD_EN_2.1
S$8: H1.4, M1.10
S$9: LCD_EN.2, LCD_EN_2.2
S$14: H1.5, M1.12
S$16: C4.2, H2.2, M1.2, R7.1
S$18: C3.1, R2.1, R3.2
S$19: H1.11, M1.16
S$20: LCD_EN.1, M1.8
S$21: H1.12, M1.15
S$22: H1.13, M1.14
S$23: M1.19, PICKIT.4, TACH.3
S$24: LCD_D7.1, M1.7
S$25: CURRENT_LIMIT.1, M1.18, PICKIT.5
S$26: C5.2, H2.4, M1.3, R8.1
S$27: LCD_D7.2, LCD_D7_2.1
S$30: M1.6, REV.2
S$31: I2C.1, M1.13
S$32: C6.2, H2.6, M1.4, MCLR.2, R9.1
S$34: M1.5, PWM.1
S$39: DRIVER_OUT.5, REV.1
S$40: CURRENT_LIMIT.2, DRIVER_OUT.4
S$41: DRIVER_OUT.3, PWM.2
V+: C2.1, H2.8, LM317LZ.2 (OUT), M1.1, P1.A, PICKIT.2, R2.2, R4.1, R7.2, R8.2, R9.2, TACH.1, VTEST.2

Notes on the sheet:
I've been using a PICKIT2 to program the PIC in circuit. A PICKIT3 will work fine. At some point it might be nice to just be able to program via the USB bootloader, however I'm out of pins :(
If you are using a PICF14k50 you can either remove the regulator if your source at POWER is a regulated +5V
The Controller & Driver are separate in my design - for isolation and such that you could possibly use the Controller with a different driver. I have had good success using ribbon cable and Molex KK connectors for cables..
The resistor + capacitor setup provides some basic switch debouncing on the tactile switch inputs.
I'm using a 24x2 Character LCD that has the 2x8 connector. Take a look at the connector boards that I have included which work well for ribbon to header connections. The LCD is setup for 4bit mode.
I2C Setup but not used thus far. Good for expansion. ELS?
DC Motor Controller by: Morgan Demers Copyright (c) 2013

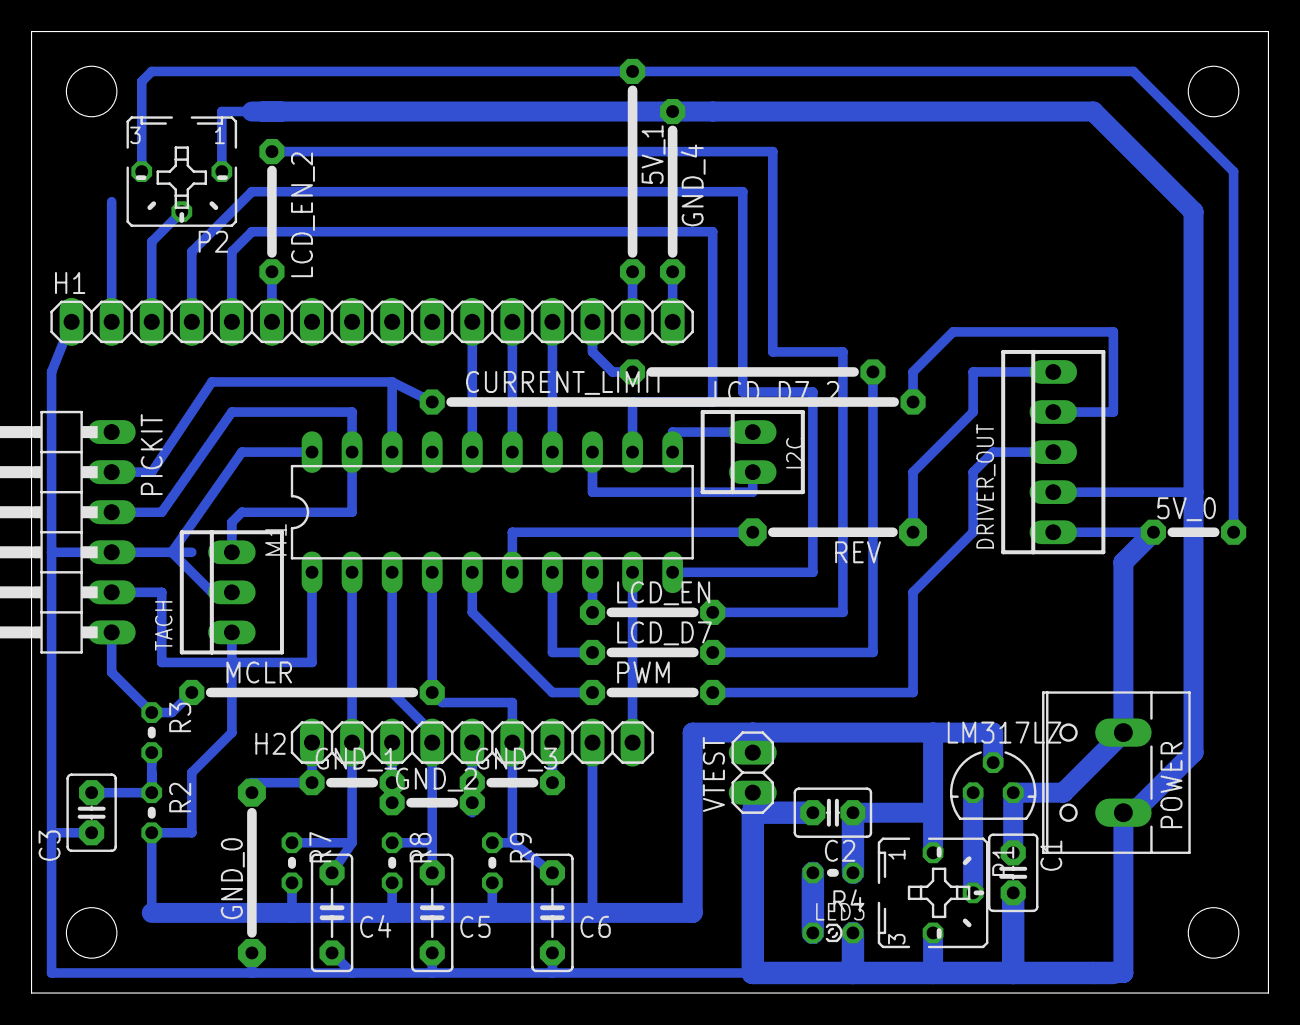
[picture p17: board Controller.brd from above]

Board: 2 copper layers, 78.4 x 61.0 mm, 40 parts (0 on the bottom side), 39 nets.

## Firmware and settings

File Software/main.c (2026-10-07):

/*
Program: DC Motor Controller
Author:  Morgan Demers
Dates:   Created: 1/9/2011
         Last Updated On: 9/13/2013

Project Website: http://morgandemers.com

Prerequisite: This code is designed to work with the Controller & 
              Driver circuits found at the 'Project Website' url 
              above. It is also designed to be run on a PIC18LF14K50,
              though should easily adapt to a PIC18F14K50. Any other
              PIC used will require the updating of the I/O pin assignments,
              other PIC settings, and probably also the modification of 
              the Controller Board Layout / Schematic. That being said, if
              you are attempting to recreate what I have done, it would be 
              ideal to follow my suggested parts list in order to achieve 
              similar results.

Disclaimer:  This is probably as polished of a product as it is going to get at
             this point. My time is fairly limited - I did my best to comment
             a lot of the code, and clean it up a bit. Feel free to make modifications
             as need be ( at your own risk ) and be sure to pay attention to the
             License below.

Description: This controller maintains speed by using a closed loop PID control
             algorithm. The feedback comes from an encoder wheel ( either with
             slots or black & white lines ) which is mounted to the main machine 
             tool spindle. If you would like to place the encoder wheel elsewhere
             you will have to modify the code to account for any pulley / gear 
             ratios... Other methods of attaining feedback could be used ( hall 
             effect sensor, etc... ) however the resolution of the encoder is 
             essential to good response times...

			 My setup ( on my Gingery Lathe ) has a 24x2 LCD display, 3 buttons and
             a knob as the interface into the controller. The knob is used to set the
             RPM target, and the 3 buttons are for 'left','menu','right'. The code 
             is fairly clever in that when the menu button is held, and the left or right
             buttons are pressed, it will allow you to rotate through an unlimited number
             of main menus. When the menu button itself is pressed you get rotated through the
             menu's sub menus. The left and right buttons are used for incrementing / 
             decrementing menu data on screen ( unless the menu button is held down ). If you 
             hold down the left or right buttons for a set amount of time, a multiplier will
             be applied to the button's value, and at a regular timed interval the menu data
             will continue to be updated until the button is no longer pressed. This allows for
             the quick modification of numbers without a keypad / many buttons. I
             have had fairly good success using this interface on my lathe, and it reduces
             the number of I/O pins drastically... If you want to change how the UI is setup
             on your particular system, you will have to make quite a few modifications both
             to the code and to the Controller's board layout / schematic. Also, at this point
             I have maxed out the PIC18LF14K50's available I/O pins, and thus you would have
             to upgrade to a PIC with more pins ( > 20pin ) which would require a big design
             change on the Controller's board layout / schematic.

			 * one possible solution to the I/O issue would be to add a helper board with an
               additional PIC18. The current controller board is setup for I2C, so you could probably 
               move the User Interface stuff onto a separate PIC18, and communicate with it via
               I2C. I'd like to do this at some point when I add ELS to my lathe, but at this 
               point I have not done any work on this as of yet...

             There are 4 parts to this program.

             a. Main Program ( this file ) - initializes PIC, Has main program
                variables, handles reading / storing settings to EEPROM, handles
                interrupts, etc...

				Basic Order Of Business:
                ------------------------
                1. PIC Initialized ( I/O pins configured, PWM setup, ADC setup, etc.. )
				2. Settings Read From EEPROM
				3. User Interface Initialized
				4. System Enters Main Program Loop
				   4i.  Timer0 Interrupts ( High Priority ) at some Sampling Frequency which 
                        flags Main Program Loop to process the sample, run PID algo, process 
                        the user interface, etc...
				   4ii. Low Priority, Interrupt on Change detected on UI Buttons, Tach input, 
                        Current limit input, or ADC RPM Knob Available - process buttons, 
                        update encoder count, etc..and whatever was changed here will be 
                        processed at next Timer0 Interrupt.

			 b. PID Library ( PID.c, PID.h ) - contains the meat and potatoes of
                the PID control algorithm. This library could be used in other programs
                as it does not care about the specifics of this particular case.

             c. User Interface Library ( UI.c, UI.h, LCD.c, LCD.h ) - Handles all the 
                User Interface processing - what to do with button changes, management 
                of which menu the user is viewing, and how to get the menu data onto the 
                LCD screen. Requires that this main program code has two functions 
                'update_menu_data' and 'render_menu' to help the UI library determine
                what should actually be displayed on the LCD, and what program variables
                need to be updated when a menu item is altered.

			 d. Helper Libraries
				1. EEPROM.h, EEPROM.c - Has functions to actually write to, read from, EEPROM
                2. Delay.h, Delay.c - Has functions to pause by second, millisecond, microsecond
				3. stdio.h, need itoa(), 

License: This work is licensed under the Creative Commons 
         Attribution-NonCommercial-ShareAlike 3.0 Unported License. 
         To view a copy of this license, visit 
         http://creativecommons.org/licenses/by-nc-sa/3.0/.

Modifications: { please list modifier name, modification date, modification description }

10/01/2013 - Morgan Demers - Changed Timer0 to operate at 500hz, and updated the current limiting code to incorporate
                            a software based low pass filter in order to prevent false triggering from the PWM
                            pulses. When the current limit detect count is greater than a set threshold current
                            limiting will take effect. The current configuration allows the system to initiate 
                            current limiting at half the 1khz frequency of the 4/23 update which may correct some
                            discrepancy Darren was seeing between his bike computer and the tach output. more data
                            is collected per tick in order to determine if current limiting should take place.

4/23/2013 - Morgan Demers - Updated Timer0 to run at 1khz such that we can use it to check for Current Limiting
                            at a fixed 1khz frequency. Have new variables SAMPLES_PER_TICK which defines how
                            frequently we want to process the PID algo, update display, etc... We also have 
                            TICKS_PER_S which is used throughout the code to determine RPM, setpoint, etc...
                            Added a new ticks[2] variable that accumulates until it is >= SAMPLES_PER_TICK at 
                            which point do_tick=1 and stuff is processed as usual... This was mainly done for
                            no-tach setups, as well as the case where the spindle is stalled and no tach 
                            readings are being made. Basically current limiting was checked whenever an interrupt
                            on changed fired, but not the best situation.

4/9/2013 - Morgan Demers - Added 'TACHOMETER_ENABLED' and 'PID_ENABLED' constants. Used throughout
                           the code to allow for 'open loop variable speed control' or 'closed loop
                           variable speed control'. The tachometer can be used in both instances...

						   Also added 'slow start' and 'slow shutdown' to prevent major current spikes
                           when starting the motor. Duty cycle ramp set with 'STARTUP_DUTY_RAMP' and 
                           'startup_duty' is where the accumulator resides for startup. 'SHUTDOWN_DUTY_DROP'
                           is where the shutdown duty cycle drop resides and 'last_duty' added to accomodate
                           that.

*/

#define XTAL_FREQ 4000000L // Set PIC Frequency (clock/4) 

// Define Controller Mode Constants
#define PID_ENABLED 1 // 1 = Closed Loop PID Control ( TACHOMETER_ENABLED 1 required ), 0 = Open Loop Control

// Define Sample Timing Constants
//
// - no point setting to higher value than
//   encoder wheel resolution.. 
//
// - My Current setup has an encoder wheel with 96 transitions,
//   you will want to modify the below definitions based on your
//   own setup...
//
// - Timer0 H:L set to the below, used to
//   set the frequency of the sampling interrupt.
#define SAMPLE_TIMER_H 0xF7
#define SAMPLE_TIMER_L 0xDC
#define SAMPLE_TIMER (unsigned int)(((unsigned int)SAMPLE_TIMER_H<<8)|(SAMPLE_TIMER_L))
#define SAMPLES_PER_S 480
#define TICKS_PER_S 96
#define SAMPLES_PER_TICK (unsigned int)(SAMPLES_PER_S/TICKS_PER_S)

// Define PWM / Motor Control Constants
#define ABSOLUTE_MAX_RPM 1500
#define ABSOLUTE_MAX_DUTY 511 // Adjust When Changing Frequency ( duty cycle resolution dependent of pwm frequency, higher frequency lower duty resolution... )
#define PWM_PERIOD 0xA0 // PWM FREQUENCY SET TO 25khz ( take advantage of 9bit duty cycle resolution )
#define PWM_PRESCALE 0x00 // 1:1 postscale, prescaler = 1

// Define Current Limiting Constants
#define CURRENT_LIMITING_ENABLED 1
#define CURRENT_LIMIT_THRESHOLD 0.50
#define CURRENT_LIMITED_COUNT (unsigned int)(SAMPLES_PER_TICK*CURRENT_LIMIT_THRESHOLD)

// Define Startup / Shutdown Constants
#define STARTUP_DUTY_RAMP 1
#define SHUTDOWN_DUTY_DROP 1

// Define Tachometer Constants
#define TACHOMETER_ENABLED 1
#define MAX_ENCODER_RESOLUTION 192 // Maximum Number of Transitions On The Encoder Wheel

// Define I/O pins
#define TACH PORTAbits.RA0  // Tachometer Sensor
#define CLIM PORTAbits.RA1  // Current Limit Sensor
#define L_BTN PORTAbits.RA3 // Interface Left Button
#define M_BTN PORTAbits.RA4 // Interface Menu Button
#define R_BTN PORTAbits.RA5 // Interface Right Button
#define M_DIR PORTCbits.RC4 // Motor Relay ( For Forward / Reverse )

// Define PWM pins / access ( currently using P1A ( RC5 )
#define PWM_EN PSTRCONbits.STRA 
#define PWM PORTCbits.RC5

// Define Where LCD is connected
#define	LCD_RS PORTBbits.RB7
#define	LCD_RW PORTBbits.RB5
#define LCD_EN PORTCbits.RC6
#define LCD_DATA PORTC

// Define System Constants
#define MAX_ADC_VALUE 1020 // Max Value Expected From Analog 2 Digital Converter

// Unique ID
#define ID 125 // Program ID #, Whenever changing EEPROM Settings Change This Number To Ensure The EEPROM Is Cleared...

// STALL DETECT Constants
#define STALL_TIMEOUT (TICKS_PER_S/5) // Number Of Timer Interrupts To Wait ( while 0 rpm ) before detecting a stall situation...

// Includes
#include <p18lf14k50.h>
#include <stdlib.h> // Need some basic string functions...
#include "EEPROM.h" // EEPROM read / write functions
#if PID_ENABLED
#include "PID.h" // Proportional / Integral / Derivative functions ( for closed loop motor control )
#endif
#include "Delay.h" // Delay functions
#include "UI.h" // User Interface functions
#include "LCD.h"

// Configuration Bits
#pragma config FOSC = IRC
#pragma config WDTEN = OFF
#pragma config LVP = OFF
#pragma config MCLRE = OFF

// SAFE START VARIABLES
static unsigned char INIT = 1; // Do Not Process Any Interrupts Until INIT=0

// Sampling Variables
static char do_tick = 0; // Notify main loop that we are ready to process next sample ( instead of calling the function in the high isr )
static unsigned int ticks[3] = {0,0,0}; // Counter variables

// Interrupt On Change Helpers
static unsigned char IOC_states[4] = {0,0,0,0}; // Stores Current States of IOC pins
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
void main(void) {
	unsigned char i = 0;

	/*
	BEGIN PIC INIT CODE
	*/

	UCONbits.USBEN = 0; // Disable USB
	OSCCON |= 0x70; // Ensure Internal Clock 16Mhz

	TMR0H = SAMPLE_TIMER_H; // Set Timer0{H:L} register for desired Sampling Time
	TMR0L = SAMPLE_TIMER_L;

	INTCONbits.TMR0IF = 0; // Clear Timer0 Interrupt Flag
	T0CON = 0x81; // 0b10000001 - Timer0 On, 1:4 prescaler ( 15.259 Hz )

	RCONbits.IPEN = 1; // Enable Priority Levels On Interrupts

	WPUA = 0x38; // Weak Pull-Ups Enabled on Port A
	WPUB = 0x00; // Weak Pull-Ups Disabled on Port B

	PORTA &= 0x00;
	TRISA = 0x30; // 0b00110000 - RA4 & RA5 = input
	IOCA = 0x00;

	TRISB = 0x00; // 0b00000000 - Port B Configured As Output
	IOCB = 0x00;

    INTCON2bits.RABPU = 0;
	INTCON2bits.TMR0IP = 1; // Set Timer0 Interrupt Priority to High
	INTCON2bits.RABIP = 0; // Set Port A & B Interrupt On Change Interrupt Priority to Low
	INTCON = 0xE8; // 0b11101000 - Global & Peripheral Interrupts Enabled, Timer0 Overflow Interrupt Enabled, Port A & B Interrupt On Change Interrupts Enabled 

	// Disable Comparators...
	CM1CON0 = 0x00;
	CM2CON0 = 0x00;

	// Disable SRQ...
	SRCON0 = 0x00;
	SRCON1 = 0x00;

	TRISC = 0x80; // 0b10000000 - RC7 = input, RC0-RC6 = output ( RC5 PWM )
	PWM = 0; // RC5 = PWM Output, Ensure 0 on pin at startup...

	// Setup PWM Timer / Pulse Steering on P1A ( RC5 )
	T2CON = 0x04; // 0b00000100 - Enable Timer2
	CCP1CON = 0x0C; // 0b00001100 - Single Output Steering, LSBs of Duty Cycle to 0, PWM Mode - P1A ( RC5 ) Active-High
	CCPR1L = 0x00; // 0b00000000 - Set MSBs of Duty Cycle to 0
	PSTRCON = 0x01; // 0b00000001 - Output Steering Update On Next Instruction

    // Setup PWM Frequency...
    T2CON |= PWM_PRESCALE;
    PR2 = PWM_PERIOD; // Set Period Register for Desired PWM Period

	// Setup ADC on AN9 For RPM Adjustment Potentiometer
	REFCON0 |= 0xB0; // 0b10110000 - FVR ( Fixed Voltage Reference ) enabled, x4 voltage ( 4.096V ) 
	ANSEL = 0x00; // 0b00000000 - RC3,RC2,RC1,RC0,RA4 digital input buffers enabled
	ANSELH = 0x02; // 0b00000010 - AN9 ( RC7 ) digital input buffer disabled, RC6,RB4,RB5 digital input buffers enabled
    ADCON2 = 0xBE; // 0b10111110 - Right Justified, 20 TAD, Fosc/64
	ADCON1 = 0x08; // 0b00001000 - Positive Voltage Reference supplied by FVR ( Fixed Voltage Reference ), Negative Voltage Reference supplied by Vss
	ADCON0 = 0x25; // 0b00100101 - Select AN9 ( RC7 ) as ADC Channel To Use, Enable ADC

	PIR1bits.ADIF = 0; // Clear ADC Interrupt Flag
	PIE1bits.ADIE = 1; // Enable ADC Interrupt
	IPR1bits.ADIP = 0; // Set ADC Interrupt Priority to Low

	/*
	END PIC INIT CODE
	*/

	DelayMs(100);

	M_DIR = 0; // Set Initial Motor Direction ( Forward - CCW )

	// Init User Interface
	ui_init();

	DelayS(2);

	// Load In Settings From EEPROM
	if( read_settings() == 0 ) {
		update_settings = 1; // Must Be First Run, Store Initial Settings To EEPROM...
	}

#if PID_ENABLED
    // Init PID Parameters...
    PID_derivative_delay = 4; // Only Process Derivative Every 4th Call to PID()
    PID_integral_delay = 1; // Process Integral Every Call to PID()
    PID_out_clamp = MAX_DUTY; // Set PID Output Clamp To MAX_DUTY
    PID_integral_clamp = MAX_DUTY; // Set PID Integral Clamp To Max_DUTY

	// Create PID Constants From Gains ( interface input fractions )
	update_ks(-1);
#endif

    // Enable Interrupt On Change Pins
#if TACHOMETER_ENABLED
	IOCA = 0x3B; // 0b00111011 - Interrupt On Change Enabled on RA0, RA1, RA3, RA4, RA5
#else
	IOCA = 0x3A; // 0b00111010 - Interrupt On Change Enabled on RA1, RA3, RA4, RA5
#endif

	// Done Initializing System, Begin Normal Operation..
	INIT = 0;

	goto_menu(0,0);

	while(1) {
		if( update_rpm_value != -1 ) { // ADC Potentiometer Data Ready To Update RPM...
			update_rpm();
		}

		if( do_tick == 1 ) { // Timer0 Interrupt Fired, Time To Process Sample / Do Other Time Sensitive Stuff...
			tick();
		}
	}
}

/*
Function: update_rpm_target
Description: Helper function for 'update_rpm()', will compute the expected encoder wheel transition 
             count for the required RPM Target ( from ADC value of RPM Adjustment Potentiometer ).
*/
void update_rpm_target(void) {
#if PID_ENABLED
	if( rpm_target >= MIN_RPM ) { // Only Process If Selected RPM Is At Least Minimum
		encoder_count_setpoint = (double)((((double)rpm_target)/60)*((double)ENCODER_RESOLUTION))/TICKS_PER_S; // Expected Transition Count per Sampling Period
	} else {
		encoder_count_setpoint = 0;
	}
#endif
}

/*
Function: update_rpm
Description: Whenever a new ADC value is available this function is called to convert the RPM Adjustment
             Potentiometer ADC value ( found in update_rpm_value ) to the actual RPM ( stored in rpm_target ).
             Uses 'update_rpm_target()' to calculate the actual setpoint for the PID control algorithm...
*/
void update_rpm(void) {
	short long t = 0; // Temporary Variable

    // Compute RPM From update_rpm_value
	t = ((short long)update_rpm_value*MAX_RPM)/MAX_ADC_VALUE;

	if( rpm_target == 0 ) { 
		rpm_target = t;
	} else {
		rpm_target = (int)((t+rpm_target) >> 1); // Do Some Simple Averaging To Smooth ADC input a bit...
	}

	if( rpm_target > MAX_RPM ) { // Clamp the Target RPM to MAX_RPM
		rpm_target = MAX_RPM;
	}

#if TACHOMETER_ENABLED
	// Call Helper Function To Compute Encoder Count Set Point For This New RPM...
	update_rpm_target();
#endif

#if PID_ENABLED == 0
	rpm_target_duty = (int)(((short long)rpm_target*MAX_DUTY)/MAX_RPM);

	if( rpm_target_duty > MAX_DUTY ) {
		rpm_target_duty = MAX_DUTY;
 	}   
#endif
	
	update_rpm_value = -1;
}

/*
Function: tick
Description: Sample Processing Routine that is called when the Timer0 Interrupt fires.
             If the system is running will use the PID library to determine the new
             PWM duty cycle in order to attain rpm_target.

             This function is also fired at a regularly timed interval, and thus other
             time sensitive code is run - for instance every second we want to update the
             Settings in EEPROM if a change was made, and also we would like to update the
             displayed RPM ( rpm_actual ) every second as well...

			 *The function is not called within the interrupt service routine as it is a
              high priority interrupt and we don't want to prevent our lower priority 
              interrupts from firing due to the processing here, so if do_tick == 1 call
              from main program loop.
*/
void tick(void) {
	int duty = 0; // Duty Cycle Variable
	short long t = 0; // Temporary Variable
	unsigned char i = 0; // Temporary Variable

   	ticks[0]++; // Update Tick Counter By 1

#if TACHOMETER_ENABLED
	encoder_count += (short long)encoder_count_last_sample; // Add Last Sample To /s Counter, used to determine RPM
#endif

#if CURRENT_LIMITING_ENABLED
	if( !PAUSED && !CURRENT_LIMITED ) { // Only Run If System Is Not Paused and Is Not Current Limited
#else
	if( !PAUSED ) { // Only Run If System Is Not Paused
#endif
#if PID_ENABLED
        if( encoder_count_setpoint > 0 ) { // Only Run If RPM Target >= MIN_RPM
            rpm_error = encoder_count_setpoint-(double)encoder_count_last_sample; // Calculate RPM Error ( actually error in setpoint vs last sample )
            duty = pid(encoder_count_setpoint,rpm_error); // Have PID control algorithm calculate new duty cycle to maintain RPM

            if( duty < 0 ) { // Ensure duty is a positive number...
                duty = 0;
            }
        }
#else
		duty = rpm_target_duty;
#endif

		// Slow Start Code...
		if( startup_duty != -1 ) {
			startup_duty += STARTUP_DUTY_RAMP;
			if( startup_duty >= duty ) {
				startup_duty = -1;
			} else {
				duty = startup_duty;
			}
		}

		last_duty = duty;
	} else if( INDEXER_ON ) {
		if( !INDEXER_DUTY_LOCK ) { // Increment Duty Until We Have A Lock On Minimum Speed To Rotate Encoder...
			INDEXER_DUTY++;
		}

		duty = INDEXER_DUTY;
	} else if( INDEXER_BRAKING ) {
		INDEXER_BRAKING--;
		if( !INDEXER_BRAKING ) {
			M_DIR = !M_DIR;
			lcd_init(); // Assume LCD Will Fail From Some Spike...
		}
    } else { // If Paused, Ensure That Nothing is Running & PID internals are reset
		startup_duty = 0;

		if( last_duty > 0 ) {
			last_duty -= SHUTDOWN_DUTY_DROP;
			if( last_duty < 0 ) {
				last_duty = 0;
			}

			duty = last_duty;
		} else {
	    	duty = 0;
		}

#if PID_ENABLED
		rpm_error = 0;
        pid_reset();
#endif
	}

	duty:
    set_duty(duty); // Set the actual PWM Duty Cycle via 'set_duty' helper function
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

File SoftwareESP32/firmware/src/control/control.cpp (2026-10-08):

#include "control.h"
#include <Arduino.h>
#include "driver/pcnt.h"
#include "soc/pcnt_struct.h"
#include "driver/mcpwm.h"
#include "freertos/semphr.h"
#include <Preferences.h>

// ---------------------------------------------------------------------------
// Fixed constants. Limits that the Settings tab edits (max/min RPM, max duty,
// encoder resolution) live in s_shared and are persisted in NVS.
// ---------------------------------------------------------------------------
static const int SAMPLE_HZ = 1000;                 // PID tick rate
static const int DEFAULT_ENCODER_RESOLUTION = 1000; // spindle encoder PPR
static const double PID_REF_CPR = 96.0;             // PID gains are normalised to this counts/rev (the original tach)
static const int16_t PCNT_LIMIT = 30000;            // hardware counter clears at +/-limit; deltas are unwrapped
static const int DEFAULT_MAX_RPM = 3000;
static const int DEFAULT_MIN_RPM = 50;
static const int DEFAULT_MAX_DUTY = 90;
static const int STATS_WINDOW_TICKS = SAMPLE_HZ / 10; // 100ms window for RPM/pulse-rate/load reporting
static const int STALL_TIMEOUT_TICKS = SAMPLE_HZ / 5;   // ~200ms, matches original PIC18 behavior
static const float OVERSPEED_MARGIN = 1.15f;             // trip if actual > MAX_RPM * margin
static const float STARTUP_RAMP_PERCENT_PER_TICK = 0.05f; // slow-start limiter

// ---------------------------------------------------------------------------
// Shared state - guarded by s_mutex. Only commanded (write side) + reported
// (read side) fields live here; PID-internal state (integral/derivative) is
// task-local and never touched by other tasks.
// ---------------------------------------------------------------------------
static SemaphoreHandle_t s_mutex;

static struct {
    // commanded
    int rpm_target = 0;
    bool running = false;
    bool direction_reverse = false;
    bool direct_mode = false; // true = bypass PID, open-loop duty from rpm_target
    float kp = 2.0f, ki = 0.5f, kd = 0.1f, ff = 0.0f;
    bool clear_fault_request = false;
    int max_rpm = DEFAULT_MAX_RPM;
    int min_rpm = DEFAULT_MIN_RPM;
    int max_duty = DEFAULT_MAX_DUTY;
    int enc_res = DEFAULT_ENCODER_RESOLUTION;
    // reported
    int rpm_actual = 0;
    int duty_percent = 0;
    bool stalled = false;
    bool current_limited = false;
    float current_amps = 0;
    float temperature_c = 25;
    int pulses_per_s = 0;
    int task_load_percent = 0;
    int spindle_dir = 0;
    int index_count = 0;
    int counts_per_index = 0;
} s_shared;

static Preferences s_prefs;

// Set by the fault-pin ISR the instant the comparator trips - informational
// only. The actual PWM shutdown already happened in silicon via the MCPWM
// trip-zone before this ISR even runs.
static volatile bool s_fault_isr_flag = false;
static volatile uint32_t s_tach_total = 0;

// Index pulse: latch the live PCNT value so the control task can place the
// pulse exactly in the unwrapped count stream, not just to its 1ms tick.
static volatile uint32_t s_index_events = 0;
static volatile int16_t s_index_raw = 0;

static void IRAM_ATTR index_isr(void *arg) {
    // Direct register read: the driver's getter isn't IRAM-safe and the HAL helper is C-only.
#if CONFIG_IDF_TARGET_ESP32S3
    s_index_raw = (int16_t)PCNT.cnt_unit[0].pulse_cnt_un;
#else
    s_index_raw = (int16_t)PCNT.cnt_unit[0].cnt_val;
#endif
    s_index_events = s_index_events + 1;
}

static void IRAM_ATTR fault_isr(void *arg) {
    s_fault_isr_flag = true;
}

// ---------------------------------------------------------------------------
// PID (ported from the original PIC18 PID.c - same clamped-integral /
// delayed-derivative / feed-forward algorithm, task-local state).
// ---------------------------------------------------------------------------
struct PidState {
    double integral = 0, last_error = 0, derivative = 0;
    bool integral_limited = false;
};
static PidState s_pid;

static double pid_compute(PidState &p, double kp, double ki, double kd, double ff,
                           double setpoint, double error, double out_clamp) {
    p.derivative = error - p.last_error;
    p.last_error = error;

    if (!p.integral_limited) {
        p.integral += error;
    }

    double out = error * kp + p.integral * ki + p.derivative * kd;
    if (ff != 0) out += setpoint * ff;

    if (out_clamp > 0 && fabs(out) > out_clamp) {
        out = out < 0 ? -out_clamp : out_clamp;
        p.integral_limited = true;
    } else {
        p.integral_limited = false;
    }
    return out;
}

static void pid_reset(PidState &p) {
    p.integral = 0;
    p.last_error = 0;
    p.derivative = 0;
    p.integral_limited = false;
}

// ---------------------------------------------------------------------------
// Hardware init
// ---------------------------------------------------------------------------
static void tach_pcnt_init() {
    pcnt_config_t cfg = {};
    cfg.counter_h_lim = PCNT_LIMIT;
    cfg.counter_l_lim = -PCNT_LIMIT;
    cfg.unit = PCNT_UNIT_0;

    // Channel 0: edges on A, direction from B.
    cfg.channel = PCNT_CHANNEL_0;
    cfg.pulse_gpio_num = PIN_TACH;
    cfg.ctrl_gpio_num = PIN_TACH_B;
    cfg.lctrl_mode = PCNT_MODE_KEEP;
    cfg.hctrl_mode = PCNT_MODE_REVERSE;
    cfg.pos_mode = PCNT_COUNT_INC;
    cfg.neg_mode = PCNT_COUNT_DEC;
    pcnt_unit_config(&cfg);

    // Channel 1: edges on B with the opposite sense (x4 decoding).
    cfg.channel = PCNT_CHANNEL_1;
    cfg.pulse_gpio_num = PIN_TACH_B;
    cfg.ctrl_gpio_num = PIN_TACH;
    cfg.lctrl_mode = PCNT_MODE_REVERSE;
    cfg.hctrl_mode = PCNT_MODE_KEEP;
    cfg.pos_mode = PCNT_COUNT_INC;
    cfg.neg_mode = PCNT_COUNT_DEC;
    pcnt_unit_config(&cfg);

    // Quadrature edges can be a few microseconds apart at high speed.
    pcnt_set_filter_value(PCNT_UNIT_0, 100);
    pcnt_filter_enable(PCNT_UNIT_0);

    pcnt_counter_pause(PCNT_UNIT_0);
    pcnt_counter_clear(PCNT_UNIT_0);
    pcnt_counter_resume(PCNT_UNIT_0);
}

static int counts_per_rev(int enc_res) {
    return enc_res * 4; // x4 quadrature decoding
}

// Shortest signed distance between two readings of the self-clearing +/-PCNT_LIMIT counter.
static int32_t unwrap_delta(int16_t now, int16_t last) {
    int32_t d = (int32_t)now - last;
    if (d > PCNT_LIMIT / 2) d -= PCNT_LIMIT;
    else if (d < -PCNT_LIMIT / 2) d += PCNT_LIMIT;
    return d;
}
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

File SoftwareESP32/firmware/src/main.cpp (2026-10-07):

/*
 * DC Motor PID Controller - ESP32-S3
 *
 * Architecture: a dedicated real-time control task (PCNT/MCPWM/PID, pinned to
 * core 1) separate from the web/WiFi stack (core 0) and a USB-Serial/JTAG CLI.
 * The web and CLI layers never touch hardware directly - they only call the
 * thread-safe command/status API exposed by control.h.
 */
#include <Arduino.h>
#include "control/control.h"
#include "dro/dro.h"
#include "web/web_server.h"
#include "cli/cli.h"

void setup() {
    Serial.begin(57600); // lowered from 115200 for more reliable comms on this board/wiring

    control_init(); // PCNT tach/encoder, MCPWM + trip-zone, PID task (core 1)
    dro_init();     // Z/X linear-scale quadrature decoders (PCNT units 1-2)
    web_init();     // WiFi, ESPAsyncWebServer, WebSocket telemetry/commands (core 0)
    cli_init();     // esp_console REPL over USB-Serial/JTAG
}

void loop() {
    // Control loop runs in its own task, web server is event-driven, CLI has
    // its own console task - nothing to do in the Arduino loop task.
    vTaskDelete(NULL);
}

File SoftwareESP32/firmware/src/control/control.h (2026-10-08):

#pragma once
#include <stdbool.h>
#include <stdint.h>

// ---- Pin assignments - differ per target since GPIO/ADC maps aren't
// portable between chip variants (flash pins, UART0 pins, and which GPIOs
// are ADC-capable all differ). CONFIG_IDF_TARGET_* is set automatically by
// the Arduino-ESP32 build for whichever board/env you build.
#if CONFIG_IDF_TARGET_ESP32S3
// ESP32-S3-DevKitC-1: ADC1 covers GPIO1-10.
#define PIN_TACH        4   // Spindle quadrature encoder A (PCNT unit 0)
#define PIN_TACH_B      15  // Spindle quadrature encoder B
#define PIN_TACH_INDEX  16  // Spindle encoder index (Z) pulse, rising edge
#define PIN_PWM         5   // MCPWM0A output -> gate driver IN
#define PIN_FAULT       6   // Current-limit comparator digital output -> MCPWM Fault0 (active-high)
#define PIN_DIR         7   // Motor direction relay output
#define PIN_CURRENT_ADC 1   // Hall-effect isolated current sensor analog output (ADC1)
#define PIN_TEMP_ADC    2   // MOSFET NTC thermistor analog input (ADC1)
#define PIN_DRO_Z_A     9   // DRO Z scale quadrature A (PCNT unit 1)
#define PIN_DRO_Z_B     10  // DRO Z scale quadrature B
#define PIN_DRO_X_A     11  // DRO X scale quadrature A (PCNT unit 2)
#define PIN_DRO_X_B     12  // DRO X scale quadrature B
#else
// Classic ESP32 (DevKitC/WROOM-32 etc): GPIO6-11 are reserved for the
// in-package flash, GPIO1/3 are UART0 TX/RX (Serial/flashing) - avoid both.
// ADC1 (usable with WiFi active) is only on GPIO32-39.
#define PIN_TACH        18  // Spindle quadrature encoder A (PCNT unit 0)
#define PIN_TACH_B      16  // Spindle quadrature encoder B
#define PIN_TACH_INDEX  17  // Spindle encoder index (Z) pulse, rising edge
#define PIN_PWM         19  // MCPWM0A output -> gate driver IN
#define PIN_FAULT       21  // Current-limit comparator digital output -> MCPWM Fault0 (active-high)
#define PIN_DIR         22  // Motor direction relay output
#define PIN_CURRENT_ADC 34  // Hall-effect isolated current sensor analog output (ADC1_CH6, input-only)
#define PIN_TEMP_ADC    35  // MOSFET NTC thermistor analog input (ADC1_CH7, input-only)
#define PIN_DRO_Z_A     25  // DRO Z scale quadrature A (PCNT unit 1)
#define PIN_DRO_Z_B     26  // DRO Z scale quadrature B
#define PIN_DRO_X_A     27  // DRO X scale quadrature A (PCNT unit 2)
#define PIN_DRO_X_B     14  // DRO X scale quadrature B
#endif

// Starts the real-time control subsystem: PCNT (tachometer), MCPWM with a
// hardware trip-zone (current-limit / overspeed cutoff independent of
// software), ADC current/temperature sampling, and the PID task pinned to
// its own core. Call once from setup().
void control_init();

// Thread-safe command API - shared by the web (WebSocket) and CLI front ends
// so both stay in sync and share the same validation/clamping logic. All
// setters clamp/validate server-side regardless of what the caller passes.
void control_set_rpm_target(int rpm);
void control_set_pid_gains(float kp, float ki, float kd, float ff);
void control_start();
void control_stop();                      // immediate stop, no ramp
void control_set_direction(bool reverse); // ignored while running
void control_clear_fault();               // required before control_start() after a stall/trip

// Bypasses the PID algorithm: duty follows rpm_target via a fixed linear
// open-loop mapping instead of closed-loop error correction. Stall/overspeed/
// hardware trip-zone protections stay fully active in either mode.
void control_set_mode_direct(bool direct);
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

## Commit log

2026-10-07 Initial commit: DC motor controller (PIC18) and ESP32 firmware, hardware, KiCad schematic
    [120VAC.sch, 1x16 to 1x16.brd, 1x16 to 1x16.sch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]
2026-10-08 Quadrature encoder spindle RPM, index pulse diagnostics, GUI/mockup updates

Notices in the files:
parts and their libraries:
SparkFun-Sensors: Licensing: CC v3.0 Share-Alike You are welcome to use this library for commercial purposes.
